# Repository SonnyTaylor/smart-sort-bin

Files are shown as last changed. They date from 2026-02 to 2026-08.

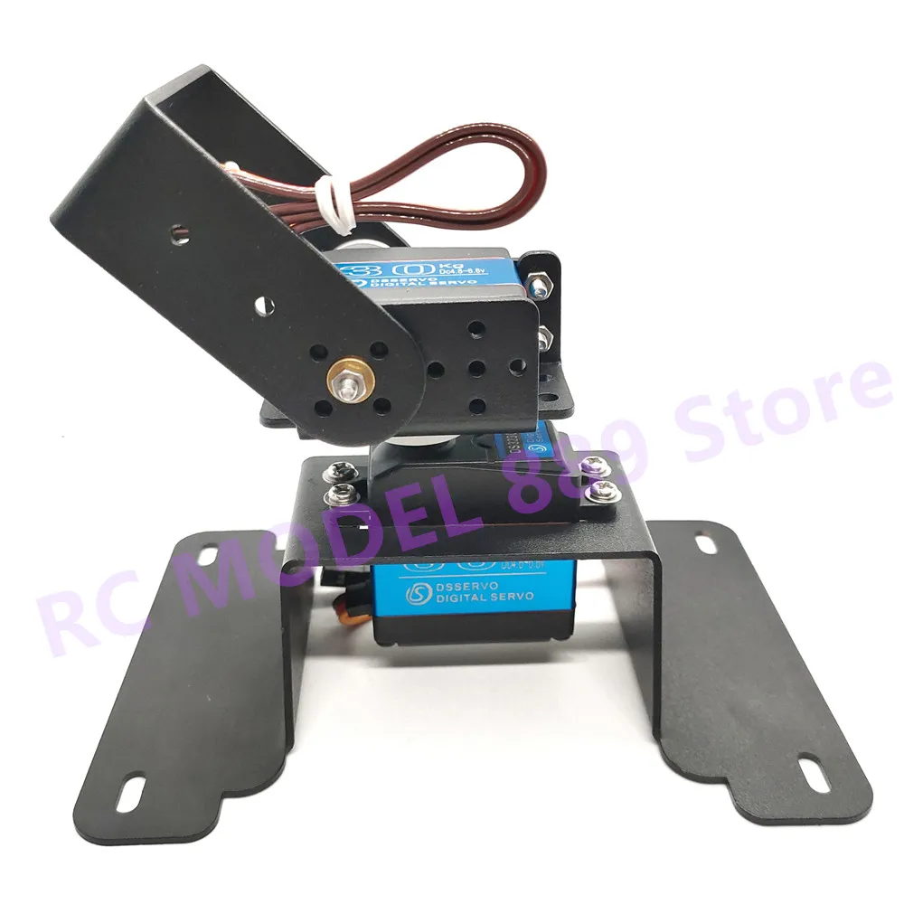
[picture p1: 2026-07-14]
portfolio/images/hardware/premade_bracket.webp

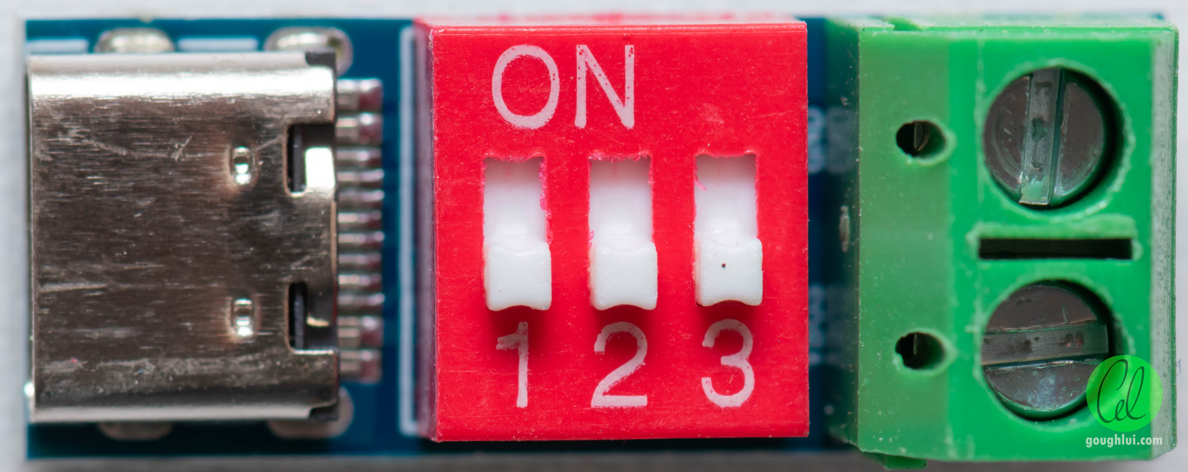
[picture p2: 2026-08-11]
portfolio/images/hardware/usbc_pd_board.jpg

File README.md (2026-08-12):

# Smart Sort Bin





An AI-powered waste sorting system that eliminates recycling contamination at the point of disposal. A camera on a pan/tilt head captures each item, a cloud Vision Language Model classifies it, and servos tip it into one of three bags hanging in the bin, all controlled from a web dashboard.

The head sits on a printed tripod that clamps across the bin rim on three PVC legs. Moving the whole thing to a different bin means cutting three new legs and nothing else.

**Build status:** electronics and software run. None of the eleven printed parts have been made yet. See the [build log](docs/build_log.md).

Developed for VCE Systems Engineering Unit 3 & 4. Inspired by the [Ameru AI Bin](https://www.ameru.com.au/).

---

## Architecture

The prototype runs entirely on a **Raspberry Pi 3B**, pivoted from the original two-board ESP32-CAM design. That iteration is written up in the PowerPoint.

```
  [ Item placed on tray ]
           |
  USB webcam captures frame (v4l2 mmap stream)
           |
  Cloud VLM classifies (OpenRouter / OpenAI / Gemini / Ollama)
           |
  Pan servo -> bin third, tilt servo -> dump, return home
           |
  Sort logged to SQLite, dashboard updates over SSE
```

| Component | Role |
| :--- | :--- |
| Raspberry Pi 3B | Runs Flask server, classification pipeline, servo control |
| USB webcam | Frame capture via `v4l2-ctl` mmap streaming |
| 2x MG996R servos | Pan (GPIO 17) and tilt (GPIO 27) via pigpio hardware PWM |
| WS2812B LED ring | Status colors (GPIO 18). Dropped from the build, code kept |
| USB-C PD trigger board | External 5V rail for servos |

## Web Dashboard

One page at `http://<pi>:8080/`:

- **Camera**: live MJPEG stream, Snap & Sort pipeline with real-time stage progress, classify-only, snapshots, model comparison (two VLMs on the same frame, side by side)
- **Servo control**: XY drag pad, fine sliders, keyboard (WASD) and gamepad input. Inputs are throttled client-side and slew-rate-limited on the Pi so motion is always smooth
- **Animations**: server-side keyframe engine with built-in moves (wave, nod, scan, figure-8, ...) plus a sequence editor to compose, preview, and save your own
- **Calibration**: set each bin's pan/tilt positions from the current head position, tune sequence timing, test a full dump without touching code
- **Stats**: totals, per-category breakdown, confidence/latency averages, 24-hour activity chart
- **Providers**: OpenRouter/OpenAI/Gemini/Ollama/custom, API keys and model IDs editable in the UI with connection tests

## Running Locally (no hardware)

Requires Python 3.11+ and [uv](https://docs.astral.sh/uv/):

```bash
cd src/web
uv run app.py --mock
```

Open http://127.0.0.1:8080. Everything works except the camera feed and physical servo motion.

## Running on the Pi

Run `python tools/deploy.py` to push the code and restart Flask.

The Pi runs `app.py --pi`, which loads the real hardware layer (`src/pi/hardware.py`) and needs the `pigpiod` daemon for jitter-free servo PWM.

The other flags, the wiring, the OS setup and the troubleshooting are all in [`docs/pi_setup.md`](docs/pi_setup.md), which is the one place the deploy commands are written out in full.

## Project Structure

```
smart-sort-bin/
├── portfolio/            # The VCE PowerPoint. ai_bin.js generates it
├── src/                  # The code that runs the bin
│   ├── pi/hardware.py    # Servos (pigpio + slew smoothing), camera, LED
│   ├── systemd/          # Service files for auto-start
│   ├── esp32/            # Dead firmware from the old two-board design
│   └── web/              # Flask app, dashboard, database, VLM providers
├── cad/                  # Fusion exports, plus the design-evolution renders
├── docs/                 # Build log, mechanical design, Pi setup notes
├── tools/                # deploy.py, check_docs.py
└── PLAN.md               # Original project plan, frozen
```

## Documentation

The VCE portfolio is a PowerPoint, generated from
[`portfolio/ai_bin.js`](portfolio/ai_bin.js) by running `bun run ai_bin.js`. It
is the up-to-date record of the risk assessment, budget, testing, iteration
history and evaluation, and it has been submitted once already.

A second deck, [`portfolio/hardware_log.js`](portfolio/hardware_log.js), builds
the hardware development log: how the mechanism was designed, in the order it
happened, and the fifteen faults caught before printing. Run `bun run
hardware-log`.

Everything else has one home, and this is the list of homes:

- [Build log](docs/build_log.md): what has actually been built, dated. **Start here**
- [Mechanical Design](docs/mechanical_design.md): how the sorting mechanism works, with verified clearances
- [Mechanical Iteration Log](docs/mechanical_iteration_log.md): fourteen faults found and corrected before printing
- [CAD](cad/README.md): parts, hardware list and assembly order
- [Design evolution renders](cad/renders/README.md): how the old versions of each part get drawn from git history
- [Pi Setup](docs/pi_setup.md): wiring, OS config, deploy commands, troubleshooting
- [Pi TODO](docs/pi_todo.md): what is left to do
- [Project Plan](PLAN.md): the original plan, frozen as a historical record

If you are an AI agent working in this repo, read [AGENTS.md](AGENTS.md) first.
It has the rules that stop these documents drifting apart, and
`python tools/check_docs.py` enforces them.

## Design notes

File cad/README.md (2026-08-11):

# CAD

The mechanical parts. **Autodesk Fusion is the source of truth.** The models
live in the Autodesk project *Systems engineerring*; everything in this folder
is exported from there.

## The parts

| Fusion document | Qty | Size | What it does |
| :--- | :---: | :--- | :--- |
| Smart Bin - hub plate | 1 | 132 dia x 4 | Holds the pan servo, spans the bin on three legs |
| Smart Bin - leg bracket | 3 | 32 x 26.4 x 36.4 | Bolts under the plate, takes a pipe |
| Smart Bin - bin clamp | 2 | 58.1 x 24.4 x 31.4 | Grips the bin rim at the far end of each pipe |
| Smart Bin - camera clamp | 1 | 58.1 x 26.4 x 66.4 | The same clamp with a 20mm socket on top for the camera post. Replaces one of the three |
| Smart Bin - camera head | 1 | 50 x 32 x 38 | Caps the camera post. Side arm carries a 1/4-20 bolt for the webcam |
| Smart Bin - pan ring | 1 | 96.3 x 111.2 x 11.5 | Traps the pan servo against the plate and carries the yoke's bearing |
| Smart Bin - tilt yoke | 1 | 60 x 116.5 x 62.5 | Turns on the ring, carries the tilt servo out past the tray |
| Smart Bin - tilt cradle | 1 | 52 x 92 x 31 | Tips the tray about the tilt axis |
| Smart Bin - sorting tray | 1 | 120 x 90 x 18 | The saddle the rubbish lands on |
| Smart Bin - box hanger | 1 | 33 x 44 x 26 | Hooks over the bin rim and carries the box below |
| Smart Bin - electronics box | 1 | 71 x 190 x 42.5 | Holds the Pi, breadboard, PD board and wiring |
| Smart Bin - assembly | | | All of the above in position, plus the bin |

Not printed: **four** lengths of 20mm PVC electrical conduit, three for the
legs and one standing up for the camera, plus two MG996R servos.

The head is our own design. It used to be a bought MakerWorld pan-tilt
tracker, which is why some older pictures show a 125mm dome under the tray.
[`docs/mechanical_design.md`](../docs/mechanical_design.md) explains how the
replacement works and why.

### The head, in one paragraph

The pan servo drops through the hub plate and hangs underneath, with its
flange trapped between the plate's top face and the pan ring. The ring's top
face is a plain bearing. The tilt yoke turns on it, bolted to the pan servo's
horn, and reaches out past the edge of the tray on both sides: the tilt servo
on one arm, a 10mm idler boss on the other. The tilt cradle spans between
them and the tray bolts to it. Tilt axis 58mm above the plate, tray underside
73mm.

### The camera post

The post goes on the **180 degree leg**, the long one, and is in the assembly.
Its axis sits 142.5mm from the tray centre, and the tray only sweeps a 75mm
radius when it pans, so nothing moving comes near it.

The camera itself sits on the head's side arm, which reaches back toward the
tray, so the **bolt axis is 122.5mm** from the tray centre. That is the number
every sighting figure below is worked from, not the post's own 142.5.

With a **235mm** length of conduit the arm's top face finishes at z=238, and the
tray's surface at its centre is at z=81, so the camera sits 157mm above the tray
and 122.5mm to one side. That is looking down about **52 degrees** from **199mm**
away. A longer pipe gives a steeper, more overhead view: the camera ends up
roughly `122.5 x tan(angle)` above the tray surface.

This was 300mm when the tray sat 65mm higher. Cutting a 300 now gives 61 degrees
from 254mm away, which still works and is actually a squarer view of the tray,
but it puts the camera further off and stands the whole thing taller.

The webcam mounts with a **1/4-20 bolt** through the head's side arm, head
recessed underneath, thread pointing up. The arm sticks out toward the tray so
the pipe is not in shot and so the bolt head is reachable.

**The post locks with an M3 screw** through a pad on the outboard side of the
socket, 26mm above the rim. The socket wall on its own is 2.97mm, too thin to
take a brass insert, so the pad stands 4mm proud of it and gives the insert its
full 5mm. Aim the camera first, then tighten. The screw tip reaches 3mm into the
bore and bites the conduit.

## The electronics box

It goes on one of the **long side walls, on the outside**, centred 63mm from the
middle of that wall toward the camera-post end. That leaves 15.5mm to the bin's
corner and 14.8mm to the nearest leg clamp, which is the tightest pair of
clearances on the part. It sticks out 77mm from the wall and hangs 42.5mm below
the rim. Nothing about it is tied to that spot; it can go anywhere there is
190mm of clear rim.

The hanger goes on first and stays there. Its thumbscrew enters **from inside
the bin**, so it is set once, before the bags go in, and the box then lifts on
and off without touching it. The box's top edge finishes level with the rim, so
cables from the hub and the camera post cross the rim and drop straight in
through the 10mm gap between the box's back wall and the bin.

Inside is **185 x 62 x 40mm**. A Raspberry Pi 3B and a half-size breadboard lie
side by side along the floor with 17mm to spare. **Measure your breadboard
first:** this is sized for the half-size 83 x 55mm board in the prototype
photos, and a full-size 165mm one will not fit beside the Pi.

Four pegs in the floor match the Pi's own 58 x 49mm hole pattern and stand it
3mm clear. The board drops on and no screws are needed.

## Folders

| Folder | Use |
| :--- | :--- |
| `stl/` | **Print from here.** Exported from Fusion at high refinement |
| `step/` | Solid models for anyone who wants to open the parts elsewhere |
| `renders/` | Makes the design-evolution pictures for the portfolio, by rendering old versions of parts out of git history. See [`renders/README.md`](renders/README.md) |
| `*.scad` | The OpenSCAD source the hub and tray were originally developed in. No longer the design source, but **do not delete**: the version history in these files is what `renders/` draws the superseded designs from |

## Exporting after a change

Open the assembly document and run
[`renders/export_from_fusion.py`](renders/export_from_fusion.py) inside Fusion.
It writes all nine parts to `stl/` and `step/` in one go, and refuses to run if
the assembly is sitting on an out-of-date version of a part.

By hand, if you prefer: **Utilities > Make > 3D Print** for STL, **File >
Export** for STEP, saved into `stl/` and `step/` under the same name.

Either way, commit the exports. They are the only copy of a Fusion part that
lives in git, and the design-evolution renders draw the current version of each
part from them.

Renders of the finished parts come out of the Fusion assembly document and land
in `../portfolio/images/cad/`.

Renders showing how a part **changed over time** are made by
[`renders/`](renders/README.md) instead, and land in
`../portfolio/images/cad/evolution/`. Those are generated from git history, so
after changing a part, re-run them and the "current" panel updates itself.

## Cutting the pipes

Three different lengths, because a three-legged thing does not sit on a
rectangle symmetrically. For the 60L ecobin (347 x 277 outside, 4.5mm corflute):

| Leg | Cut to |
| :--- | :--- |
| 60 deg | 103.73 mm |
| 180 deg | 118.00 mm |
| 300 deg | 103.73 mm |
| camera post, standing up off the 180 deg clamp | 235 mm |

Change the bin and the three leg lengths change. The old `splitter_hub.scad`
still works out the figures from bin dimensions if you need them for a
different bin. The camera post does not depend on the bin, only on how steeply
you want the camera to look down.

## Hardware

24 x M3 brass heat-set inserts: 6 in the bracket feet, 6 in the pipe lock pads,
3 in the clamp jaws, 3 in the pan ring, 4 in the tilt cradle, 1 in the box
hanger, 1 in the camera post lock pad.

| Qty | Screw | Into |
| ---: | :--- | :--- |
| 6 | M3 x 8 countersunk | plate, down into the bracket feet. **Not longer:** past 9mm it bottoms out |
| 6 | M3 x 8 | pipe locks, down through the pads onto the conduit |
| 3 | M3 x 10 | up through the plate's spokes at R=50 into the pan ring. These are what clamp the pan servo |
| 4 | M3 x 12 countersunk | tray, down into the tilt cradle |
| 1 | M3 x 10 + washer | through the cradle's idler wall into the yoke's boss. Self-taps into a 2.5mm pilot |
| 3 | M3 x 16 or 20 | clamp thumbscrews. 16 leaves 2.4mm of travel, 20 leaves 6.4mm |
| 1 | 1/4-20 UNC x 12 or so | camera head, up through the side arm into the webcam. Hex head sits in the 11.5mm recess underneath. Any tripod screw works |
| 1 | M3 x 16 | box hanger jaw, entering from **inside** the bin. Crosses a 7.5mm gap to a 4.5mm wall with 3.5mm to spare. A 20 also fits |
| 1 | M3 x 10 | camera post lock, through the pad on the socket. Reaches 3mm past the bore onto the conduit |

The servos are fixed with **the small screws that came in their own bag**, not
with M3:

| Qty | Screw | Into |
| ---: | :--- | :--- |
| 4 | servo mounting screws | tilt servo flange, into 2.5mm pilots in the yoke's tower wall |
| 4 | servo horn screws | pan horn, up into the yoke's skirt |
| 4 | servo horn screws | tilt horn, through the cradle's driven wall |

**The pan servo takes no screws at all.** Its flange sits in a 2mm pocket and
the pan ring clamps it down; the case sits in a 41.6 x 21mm slot which is what
actually takes the panning torque. That is deliberate, and the reason is in
[`../docs/mechanical_iteration_log.md`](../docs/mechanical_iteration_log.md).

## Assembly order

1. Melt the inserts in. Everything is easier before anything is bolted together.
2. Bracket feet to the plate, countersunk screws from above so the heads finish
   flush.
3. Pipes into the brackets, lock screws down through the pads.
4. Clamps onto the far ends of the pipes, lock screws down. The **camera clamp**
   goes on the 180 degree leg, the long one.
5. Drop the assembly over the bin and nip up the three thumbscrews.
6. **Pan servo down through the plate's centre slot from above**, cable first,
   body hanging underneath, flange flat on the plate. The body points along the
   180 degree spoke, the same way as the long leg.
7. Pan ring over it, three M3 x 10 up through the plate's spokes. The ring
   traps the flange; nothing screws into the servo.
8. Tilt servo into the yoke's tower, its four own screws through the flange.
9. Pan horn onto the pan servo's shaft, then the yoke down onto it. Four horn
   screws up through the skirt, then the servo's centre screw through the 9mm
   hole in the middle. **The yoke's weight sits on the ring, not on the horn.**
10. Tilt horn onto the tilt servo's shaft. Cradle over it: horn into the pocket
    in the driven wall, four horn screws, then the idler screw and washer
    through the far wall into the yoke's boss.
11. Tray onto the cradle, four countersunk screws.
12. Camera post into the camera clamp's socket, head onto the top of it, webcam
    bolted to the head's side arm. Aim it before you tighten anything.
13. Box hanger over the rim on a long side wall, thumbscrew tightened from
    inside the bin. Then drop the electronics box onto its cleat. The box only
    goes on one way round, and it lifts straight off again.

Centre both servos in software before step 9, or the head will be built at an
angle and the whole travel will be off to one side.

## Three things to measure before you print

**The tilt servo's flange holes.** The yoke's four pilot holes are on a
48 x 8.5mm pattern, taken off the servo model. The figure quoted in most places
online is 49.5 x 10mm. Those cannot both be right, and 0.75mm a side is enough
to stop the screws going in. Put calipers across the real flange. Nothing else
in the design depends on this number, on purpose, but the yoke does.

**The servo horns.** The yoke and the cradle each have a 25.5mm round pocket for
a horn, with four 2.5mm pilots on a 16mm circle. MG996R horns vary between
sellers. Measure yours and say so if it is not a 25mm round one.

**The inserts.** M3 inserts run 4.0 to 4.6mm outside depending on supplier. Every
insert hole here is 4.2mm. Measure yours, and if they differ the holes need
changing before you print anything.

## Printing

Printer is a **Bambu Lab P1S**, 0.4mm nozzle, PLA. Fourteen pieces off eleven
designs. Everything fits the 256mm bed with room to spare; the longest part is
the electronics box at 190mm.

Every orientation and support call below was worked out from the exported
meshes, not from looking at renders. For each of the six ways a part can sit,
the downward-facing area was measured and split into patches that share an
edge, so a window's short bridge is not confused with a curved surface hanging
in air. A patch is treated as bridgeable up to 12mm across its narrow way.

### Orientation and support, part by part

The STLs are exported in the orientation the part is modelled in, so "as
loaded" means drop it on the plate and print. Where a rotation is needed, apply
it in the slicer and **check the height matches**: that is how you know you
rotated the right way, since the wrong way round gives the same footprint.

| Part | Qty | Rotate | Height when right | Support |
| :--- | :---: | :--- | ---: | :--- |
| plate | 1 | As loaded, either way up | 4.0mm | None |
| bracket | 3 | -90 about Y | 32.0mm | None |
| clamp | 2 | As loaded | 31.4mm | None |
| camera_clamp | 1 | 180 about X | 66.4mm | One patch, 20 x 21mm |
| camera_head | 1 | As loaded | 38.0mm | None |
| pan_ring | 1 | As loaded | 11.5mm | None |
| tilt_yoke | 1 | As loaded | 62.5mm | One patch, 25.5 x 25.5mm |
| tilt_cradle | 1 | 180 about X | 31.0mm | None |
| tray | 1 | As loaded, trough up | 18.0mm | Yes, most of the underside |
| box_hanger | 1 | 180 about X | 26.0mm | None |
| electronics_box | 1 | As loaded, open side up | 42.5mm | None |

`tray_mount` is not in the build, but it is worth printing as a test rig, see
below. It goes **180 about X**, 18.0mm tall, no support.

**Eight of the eleven need no support at all**, which is the payoff from the
45 degree flanks the sockets were given when they were shelled. Three do:

- **camera_clamp**: 363 mm2 at 27mm up, the roof that closes the camera post's
  socket and stops the pipe pushing through. Flat and 20mm across, too wide to
  bridge.
- **tilt_yoke**: 427 mm2 at 3mm up, the roof of the 25.5mm servo horn pocket.
- **tray**: about 8.6 cm2, nearly the whole underside.

### What kind of support

**Normal, not tree, and "on build plate only" for all three.** Each overhang
was checked by dropping a ray from the middle of it: all three have clear air
straight down to the plate, so the support stands on the bed and never has to
start on the part.

That one setting is also the safety catch. On "everywhere" the slicer is free
to fill the blind insert holes and the pipe sockets, because those have model
material at the bottom for support to sit on. On "build plate only" it cannot,
so the holes stay clear without anyone having to police them.

Tree support is the wrong shape for all three of these. Two are single flat
roofs, which normal support handles with a plain block, and the third is inside
a 20mm tube, where a tree tangles and will not come out.

| Part | The support is | Getting it off |
| :--- | :--- | :--- |
| tilt_yoke | a 25.5mm disc, 3.2mm off the plate. Three layers of nothing | Lifts off. It is the horn pocket, so a rough face there does not matter |
| camera_clamp | a 20mm column 27mm tall, standing inside the socket bore | The bore is open at the bed, so push the column straight out with a screwdriver from underneath |
| tray | a bed of support under most of the underside, carrying the part | Peels off. Only the four bolt pads matter, and support leaves those flat |

Set **top Z distance to one layer, 0.2mm**, so support breaks away instead of
welding on. On the camera clamp keep the interface layers low for the same
reason: that face is only an end stop for the conduit and it wants to come
apart cleanly, not look nice.

The tray is the one carrying real weight on its supports, since the part
balances on two end edges with no flat contact anywhere. Give it a **brim** and
do not run the support density down to the sparse end.

Turn support **off** for everything else. Left on auto, the slicer will put
support inside the pipe sockets and the insert holes, and digging it back out
of a 20mm bore is worse than the problem it solves.

### The tray is the awkward one

It is a saddle: a trough running the long way that the rubbish lands in, with
the sides raised 7.7mm to stop things rolling off, and both ends falling away
5.8mm so the load slides out when it tips. That shape has **no flat face
anywhere**, so laid down it touches the bed on two end edges and nothing else.

Print it **trough up, with supports**, and add a brim. Two reasons, and neither
is about saving support material:

- The trough is the surface rubbish has to slide off. Support marks belong on
  the underside, which only meets the cradle at four bolt pads.
- Laid flat the layers stack the way the load presses them together. Stood on
  end, which does cut the support from 8.6 to 0.3 cm2, the layers become
  vertical planes and the saddle can split along one under a side load, on a
  part 120mm tall standing on 36 mm2 of bed.

If it does come out badly, standing it on end is the fallback, not the plan.

### Settings

Starting point, not gospel. Nothing here has been printed yet.

| | |
| :--- | :--- |
| Layer | 0.2mm |
| Walls | 4 on the brackets, clamps, yoke and cradle. 3 elsewhere |
| Infill | 25% gyroid on anything holding a load, 15% for the electronics box |
| Brim | Tray and camera clamp only |

Four walls where the brass inserts go, because an insert melted into a 4.2mm
hole eats most of a 3-wall skin and the screw then pulls out through the side.

**Leave the door open and the glass lid off.** The P1S is enclosed, and PLA on
a long print in a hot chamber softens in the throat and jams. None of these
parts needs the enclosure.

### What to print first

**It depends on what you have in your hands**, because a test print is only
worth printing if there is something to check it against.

**Once the conduit and the inserts arrive, print one bracket.** It is the
smallest structural part at 14.7 cm3 and the only one that tests three of the
unknowns above at once: an insert hole, a socket that has to fit real 20mm
conduit, and an M3 lock screw. Melt an insert in, push an offcut of conduit
into the socket, and drive the lock screw before committing the other thirteen
pieces. If those fit, the rest follows in assembly order.

**Before then, the bracket proves nothing**, and neither do the clamps, the
camera clamp, the plate, the box or the hanger. Every one of them is checked
against the bin, the conduit or the inserts. What can be checked today is
whatever meets the **servos, the horns and the webcam**, since those are
already here:

| Print | cm3 | What it settles |
| :--- | ---: | :--- |
| camera head | 18.8 | The webcam's 1/4-20 screws into the side arm. No support, quick |
| tilt yoke | 39.3 | The tilt servo's flange pattern, which is the one number in this document most likely to be wrong, plus the 25.5mm horn pocket |
| tray + tray mount | 48.6 | A working tip test on the bought pan-tilt, before any of the new head exists |

**The tray and the tray mount are the interesting pair.** `tray_mount` is a
superseded part and is not in the final build, but it is the adapter between
the tray's four bolts and the bought MakerWorld pan-tilt, so printing the two
together puts a real tray on a real moving head now. Measured off the meshes:
the tray's four 3.4mm holes and the mount's four 4.2mm insert holes are both on
a 32 x 15mm pattern, and the mount takes two more screws 15mm apart underneath
into the bought bracket.

That rig tips actual rubbish, which is the only thing on this list that tests
whether the design works rather than whether it fits. It needs four brass
inserts in the mount, so if those have not arrived, dry-fit it and hold it
together for the test rather than waiting.

### How much filament

| | cm3 | PLA at 1.24 g/cm3 |
| :--- | ---: | ---: |
| All 14 pieces, solid | 354.5 | 440 g |
| Sliced estimate, walls and infill | | **200 to 265 g** |

The solid figure is measured off the meshes and is exact. The sliced figure is
an estimate at 45 to 60% of solid, which is the usual range for parts this
chunky at these wall and infill settings. Only the slicer knows the real
number. Either way a 1kg spool covers the build with room for a reprint.

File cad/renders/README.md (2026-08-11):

# Design evolution renders

This folder makes the "here is how the design changed" pictures for the
portfolio.

Two sources, and the split matters:

- The **current** version of each part is rendered from a **Fusion export**,
  because Fusion is the design source of truth.
- The **superseded** versions are rendered from the OpenSCAD files **as they
  were at the commit they lived in**. Those versions predate the move to
  Fusion, so git history is the only place they still exist.

Either way the images are the real designs rather than something redrawn
afterwards. That is the point: evidence, not illustration.

Output lands in [`../../portfolio/images/cad/evolution/`](../../portfolio/images/cad/evolution).

| File | What it is |
| :--- | :--- |
| `<family>.png` | The comparison strip: every version of one part, left to right, with a caption under each |
| `parts/<stage>.png` | Each version on its own, cropped, if you want to place one somewhere else |

---

## Running it

Three steps. Export from Fusion, render, lay out.

**1. Export the current parts from Fusion.** Open the *Smart Bin - assembly*
document, then run [`export_from_fusion.py`](export_from_fusion.py) inside
Fusion, either through the Fusion MCP connector or Fusion's own Scripts and
Add-Ins dialog. It writes `cad/stl/` and `cad/step/`, and refuses to run if the
assembly is sitting on an out-of-date version of a part.

Skip this step only if no part has changed in Fusion since the last time you ran
it.

**2 and 3. Render and lay out.**

```powershell
cd cad\renders
.\render.ps1
python compose.py
```

Takes about three minutes, most of it the tray, which has a curved surface and
20,000-odd facets.

Working on one part only:

```powershell
.\render.ps1 -Only tray
python compose.py tray
```

Seeing what would run without running it:

```powershell
.\render.ps1 -WhatIf
```

**Needs:** OpenSCAD (path is in `stages.json`) and Python with Pillow
(`pip install pillow`).

---

## Adding a new version

Everything is driven by [`stages.json`](stages.json). To add a version, add an
entry to that part's `stages` list. Nothing else changes.

```jsonc
{
  "name": "tray_4_ribbed",          // the output filename
  "label": "v4",                    // shown above the caption. "current" prints in red
  "source": { "file": "cad/tray.scad", "part": "tray" },
  "caption": "What changed and why.\nKeep it to three lines."
}
```

A stage's `source` is one of three things:

| Source | Renders | Use for |
| :--- | :--- | :--- |
| `{"stl": "cad/stl/plate.stl"}` | A Fusion export | **The current version of anything.** Fusion is the source of truth |
| `{"commit": "abc1234", "file": "cad/tray.scad", "part": "tray"}` | That file as it was at that commit | Superseded versions, which predate Fusion |
| `{"file": "cad/tray.scad", "part": "tray"}` | The OpenSCAD working copy | A part that never made it into Fusion, like the spacer |

Find the commit for a past version with:

```powershell
git log --oneline --follow -- cad/tray.scad
```

### Turning the current version into history

When a part changes enough to be worth a picture, the old "current" panel
becomes a historic one. Since the current panel is a Fusion export and Fusion
versions do not live in git, capture it **before** you change the part:

1. Run the export script and commit the STL, so that geometry is pinned in git
   history under a commit you can name.
2. Change the part in Fusion.
3. Re-export, then add a stage pointing at `{"commit": "<that commit>", ...}`.

If you forget, the old shape is still in Fusion's own version history, which you
can open from the data panel and export from.

### Why the OpenSCAD files still matter

The hub and tray were originally drawn in OpenSCAD and have since been rebuilt
in Fusion. The `.scad` files are no longer the design source, but their git
history is the only copy of the early versions. That is why they stay in the
repo.

---

## The bits that were fiddly

Worth knowing before changing the scripts, because each of these cost time.

**Parts stay comparable in size.** Every version of one part is rendered from
the same camera distance (`camera` in `stages.json`, shared by the family), and
`compose.py` then scales the whole family by a single factor. This is what makes
"the plate went from 160g of filament to 84g" visible instead of just claimed.
Do not let the layout scale each image to fit its own box.

**Full geometry, not preview.** `--render=cgal`. Without it OpenSCAD draws the
fast preview, where coincident faces z-fight and parts come out striped orange.
Note that this build of OpenSCAD needs a value: plain `--render` is a usage
error.

**PowerShell has to be told to wait.** `openscad.exe` is a GUI binary, so `&`
does not reliably block until it finishes and the script races ahead to an image
that is not written yet. Hence `Start-Process -Wait`.

**Which also has to be told to quote.** `Start-Process -ArgumentList` joins an
array on spaces without quoting anything, and this repo lives under
`C:\Users\Sonny Taylor\`, so every path split in half and OpenSCAD printed its
usage message. The script quotes the arguments itself.

**Choosing the part.** These `.scad` files build one part at a time, chosen by a
`PART` variable near the top. Rather than pass `-D PART="clamp"`, which is
awkward to quote through PowerShell into a native binary, the script rewrites
that one line in a scratch copy. It errors if it cannot find the line, so a
renamed variable will not silently render the wrong thing.

**The background is dropped out.** `compose.py` treats the render's top-left
pixel as the background colour and cuts everything matching it, keeping the
soft edge so the part does not look jagged. That is why the strips sit on white
rather than on OpenSCAD's grey.

---

## What is in here

| Path | |
| :--- | :--- |
| `stages.json` | The manifest. The only file you normally edit |
| `export_from_fusion.py` | Run inside Fusion. Writes the current parts to `../stl/` and `../step/` |
| `render.ps1` | Renders each version, from a Fusion export or from git history |
| `compose.py` | Crops the renders and builds the labelled strips |
| `raw/` | Untouched renders. Regenerated, not committed |
| `src/` | The scratch `.scad` files pulled from history. Regenerated, not committed |
| `logs/` | OpenSCAD's output per stage, including the model's own echoed calculations. Look here when a render fails |

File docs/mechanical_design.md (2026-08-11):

# Mechanical Design

*How the sorting mechanism works and why it is shaped the way it is. The
iteration history behind these decisions is in
[mechanical_iteration_log.md](mechanical_iteration_log.md).*

---

## The problem

Sort an item into one of three compartments of an ordinary wheelie-style bin,
without modifying the bin, using two servos.

## The solution in one line

A printed tripod clamps across the bin's rim and carries a pan-tilt head. The
item lands on a tray, the head turns to face a compartment, the tray tips, and
the item free-falls in.

---

## 1. The tripod hub

Three lengths of 20mm PVC electrical conduit radiate from a printed plate to
three clamps that grip the bin rim.

**The legs are structure, not chutes.** Rubbish never goes through them. It tips
off the tray and falls past them. This is what keeps the mechanism small: the
only thing that has to be printer-sized is the hub, and the span is a pipe you
cut to length.

**Bin size is a pipe length.** Changing bins means cutting three new pipes, not
reprinting anything. For the 60L ecobin the three legs come out at 103.73,
118.00 and 103.73mm, and the fact that they differ is exactly the point: three
legs at 120 degrees cannot reach the walls of a rectangle at equal distances.

This is the design's main idea, and every other decision protects it. The clamp
shape (below) is what lets it grip a bin of any shape, and using bags rather
than cut dividers (section 4) is what stops the compartments tying it back to
one bin.

### Why the legs sit at 60, 180 and 300 degrees

The drops go at 0, 120 and 240, midway between the legs. If they lined up, the
tray would fling items straight into a leg.

It also means **the legs are the dividers**. Three legs 120 degrees apart cut
the bin opening into three sectors, and each drop aims at the middle of one. No
separate divider part is needed, which is the second job the legs are already
doing.

### Why the clamp is shaped oddly

Three legs at 120 degrees cannot all meet a rectangular bin's walls square on.
On the ecobin one leg is square to its wall and the other two are 30 degrees
off.

So the fixed jaw is a **vertical rounded rib**, which touches the wall along a
line, and the thumbscrew pushes a **single point** at it from the other side. A
line plus a point pinches at any angle. The same clamp therefore grips a
rectangular bin, a round bin or a cardboard box, with no adjustment.

The outer post is deliberately narrow at 9mm. A wall arriving at an angle sweeps
sideways across the jaw, and a wide outer plate would foul it before it seated.

### Printing without supports

Every pipe socket bore is a **truncated teardrop**, not a circle: a flat-topped
45 degree peak over a round bore. That is what lets a sideways hole print with
no support. A round pipe still slides in.

### Why the sockets are shells, not blocks

A pipe socket is a round hole in a square block, so its wall is thin where the
bore is widest and thick in the four corners. Measured on the old clamp: 1.49mm
at the equator and 6mm in the corners, for a block that was 36% plastic and 64%
air. The corners were carrying nothing. They were there because a rectangle is
what you get when you extrude a rectangle.

The outer face now **follows the bore**, offset 2.5mm, with 45 degree flanks so
it still prints without support. The result is a constant-thickness shell that
is nowhere thinner than the wall it replaced, and the six socketed parts drop
from 114.3 to 95.0 cm3.

Two corners are kept rather than cut, and the reason is the same in both cases:

| Part | Bottom corners | Why |
| :--- | :--- | :--- |
| Bin clamp | cut | Nothing is under the block. Its load goes sideways into the jaw |
| Camera clamp | kept | The block's underside **is** the lid of the post socket and the seat the post's end butts against |
| Leg bracket | kept | The tube walls are 25mm apart and have to land on the foot. Cutting them pinched the load path to a 9mm strip |

So the rule is: **cut a socket's corners only where nothing is attached below
it.** Above the bore, where every one of these parts is open air, the corners
always go.

---

## 2. The tray

A shallow saddle, 120 x 90mm, 3mm shell. Mathematically a hyperbolic paraboloid:

```
z = 10 * (y/45)^2  -  5 * (x/60)^2
```

**No rim anywhere.** A rim would trap the item exactly when you are trying to tip
it out, which is the opposite of the job. The surface runs out to a thin edge.

| Direction | Shape | Why |
| :--- | :--- | :--- |
| Across (the tilt axis) | curls **up** 10mm | When the head pans, the item is thrown sideways. This gentle valley rolls it back to the middle. It is the only retention there is, and it works with gravity rather than blocking anything |
| Along (the dump direction) | curls **down** 5mm | Where the item leaves. Curling down means there is nothing to climb, so it goes as soon as it tips |

**Why 5mm and not more.** At 5mm the steepest slope is 9.5 degrees, well under
the roughly 19 degrees at which plastic starts sliding on PLA. So the item stays
put until the tray is actually tipped. Past about 8mm you are relying on luck.

Print it matte white or grey. The camera classifies the item against this
surface, so a busy or shiny background costs accuracy.

---

## 3. The head

The head was a bought MakerWorld pan-tilt tracker. It is now three printed
parts of our own, because the bought one put the tray **147mm above the bin
rim** and 85mm of that was its own stacking. The measurements, and the reason
it could not just be shimmed lower, are in
[mechanical_iteration_log.md](mechanical_iteration_log.md).

### Why a hobby pan-tilt is tall

A standard pan-tilt stands its tilt servo on end inside a U-bracket. An MG996R
is 40.7mm long with its output shaft 10.2mm off centre, so mounted that way the
**body finishes 37mm above the tilt axis**. The tray then has to clear the
servo before it clears anything else, and that alone sets the height. Everything
below it, the base and the pan servo, is stacked underneath again.

### What replaced it

**The pan servo drops through the hub plate.** Its flange sits in a 2mm pocket
on the plate's top face and the *pan ring* clamps it there; the body hangs
underneath, inside the bin, where there was nothing anyway. That deletes the
tracker's 125mm dome outright, and with it the 27mm the dome stood above the
plate and the 14.5mm gap above the servo.

**The tilt servo goes beside the tray, not under it.** This is the part that
buys the height. Hanging it below the tilt axis was tried first and does not
work: the tray sweeps a circle about that axis, so at 45 degrees of backward
tilt it comes down into the servo. But the tray is only 90mm wide and it tilts
about a **y-parallel axis**, so it sweeps in x only. Move the servo out past
y = 45mm and the tray can never reach it, at any angle.

So the *tilt yoke* turns on the ring and reaches out past both edges of the
tray: the tilt servo on one arm, a 10mm idler boss on the other. The *tilt
cradle* spans between them and carries the tray.

### What sets the height now

Not the servos. **The tray's own swing.** At 60 degrees its far corner reaches
44.5mm below the tilt axis, so the axis cannot come closer than that to the hub
plate. The axis sits at z=58 and the tray's underside at z=73, which is 82mm
above the bin rim against 147mm before.

| | Before | After |
| :--- | ---: | ---: |
| Tray underside above the rim | 147 mm | 82 mm |
| Plastic in the head | 138.4 cm3 | 100.8 cm3 |
| Printed parts in the head | 4 bought + mount | 3 |

### How far it can actually tip

The dump angle is a software number set from the Calibration tab, and **the
mechanism runs out before the servo does.** Measured by swinging the exported
tray mesh about the tilt axis, which was read off the cradle's horn pocket and
the yoke's idler boss at x=0, z=58, and checking it against the pan ring and
the hub plate:

| `tilt_dump` | Angle | Tray's lowest point | Gap to the pan ring |
| ---: | ---: | ---: | ---: |
| -0.60, the default | 54 deg | z = 18.3 | **8.3 mm** |
| -0.67 | 60 deg | z = 13.5 | 5.1 mm |
| -0.78 | 70 deg | z = 6.7 | 1.6 mm |

Contact lands somewhere near -0.85. Under about 2mm these figures are vertex
to vertex on a tessellated mesh and should not be read finer than that.

**Keep `tilt_dump` at -0.70 or shallower.** The Calibration tab accepts
anything down to -1.0 and there is nothing in the mechanism to stop the tray
arriving at the pan ring. This is deliberately not clamped in code: what a
given number means in degrees depends on which spline tooth the horn went onto,
so the real limit has to be found when the head is first assembled and centred.
Find it then, by hand, before running a sort.

This is also the answer to whether the head can be made shorter. It cannot, by
much. Lowering the tilt axis spends that 8.3mm one for one, so there is about
5mm in it before the tray starts clipping the ring at the normal dump angle.

### The bearing

The yoke's weight sits on the pan ring's top face, not on the servo horn. A
servo spline is for torque, not for carrying a cantilevered tray. The horn only
turns the yoke; a 60mm annular face takes the load and the overturning moment
from the tilt servo hanging out at y=66.

### Nothing screws into the pan servo

Its flange is trapped rather than bolted. The servo model gives the flange hole
pattern as 48 x 8.5mm and the figure quoted online is 49.5 x 10mm, and those
cannot both be right. A clamp does not care. The case sits in a 41.6 x 21mm
slot, and that is what takes the panning torque.

---

## 4. The three compartments

Three ordinary bin bags, bulldog-clipped to the rim and to the two legs either
side of them. One bag per sector. **No divider part is printed or cut**, because
the legs already divide the opening.

### Why this works, in numbers

Measured off the assembly with the bin in place:

| | |
| :--- | :--- |
| Tray underside above the bin rim | 82 mm |
| Tray underside above the bin floor | 202 mm |
| Item leaves the tray at a radius of | about 60 mm |
| Fall time from that height | 0.20 s |
| Bin wall along the three drop directions | 169, 155, 155 mm |

At a slow tip, roughly 0.3 m/s, an item lands about 120 mm from the centre. At
0.8 m/s it would reach 220 mm, which is past the wall.

The important consequence: **nothing lands near the middle.** The three sectors
converge at the hub, and that is exactly where no item falls, so the one place
bags would fight each other never gets used.

### What this trades away

- Bags sag, and once fairly full they bulge into each other. This is a
  three-quarters-full solution, not a brim-full one. Rigid dividers would not
  have that problem.
- The landing distance spread above is wide enough that a fast tilt throws items
  at the wall. **Tip speed has to be calibrated on the real thing.** It is a
  software number rather than a reprint, which is the advantage of doing the
  motion with servos.

### Why not corflute dividers

Corflute was the original plan and was in the budget. Bags win on the things
that come up every time you use it: a bag lifts straight out, where corflute
means lifting rubbish over a wall; a bag holds liquid; it is about $5 against
$15; and it needs no cutting and no new CAD.

**But the real reason is that corflute would have broken the one property the
whole design is built around.**

The clamp is deliberately shaped to grip a rectangular bin, a round bin or a
cardboard box, and changing bins is meant to cost nothing but three new pipe
lengths. Corflute dividers would have undone that: every new bin needs three
panels cut to that bin's exact cross-section, and a round bin needs curved ones.
The adaptable half of the design would have been dragged back down to one
specific bin.

Bags do not care what shape the bin is. So the fit-any-bin claim now holds all
the way through:

| To move the whole thing to a different bin | |
| :--- | :--- |
| Printed parts | none change |
| PVC legs | cut three new lengths |
| Clamps | no adjustment, they pinch at any angle |
| Compartments | clip the bags to the new rim |

That is the entire changeover. Three saw cuts.

---

## 5. Getting three bins out of a 180 degree servo

Tilting the tray **backward** throws the item 180 degrees opposite to where the
pan is aiming. Every pan position therefore covers two directions, and three
drops 120 degrees apart need only 120 degrees of pan:

| Drop | Pan | Tilt |
| :--- | :--- | :--- |
| 0 deg | 0 | forward |
| 120 deg | 120 | forward |
| 240 deg | 60 | backward |

Without this the mechanism would need 240 degrees of pan and a servo upgrade.

---

## 6. Where the electronics live

The Pi, the breadboard, the PD trigger board and the wiring hang in a box on the
**outside** of the bin rim, on a separate hanger that stays on the bin when the
box is lifted off.

### Why not underneath

Underneath the hub is the obvious place and it does not work. The three leg
brackets hang to 27.4mm below the rim, so a box has to start below them, and
that is exactly where the three bags converge. Getting the Pi out would mean
reaching through the rubbish, and the box would have to bolt to the hub plate.
Outside the rim costs nothing but 77mm of stick-out and keeps the electronics
clean, dry and at hand height.

### The weight goes into the rim, not into friction

The tripod's three clamps hold themselves on by pinching the wall between a rib
and a thumbscrew. That works there because the plate spans the bin and the load
is shared three ways. One hanger carrying about 300g on a 33mm arm is a
different problem, so the hanger **hooks over the rim** instead: a slot with a
flat roof sits on the top edge of the wall and the thumbscrew only stops it
lifting or sitting crooked.

The jaw itself is the bin clamp's, unchanged in principle: a vertical rounded
rib on one side, a single screw point on the other, so it grips a rectangular
bin, a round bin or a cardboard box. The fit-any-bin property survives.

### Why it is two parts

An open-topped box prints open side up, every wall vertical and nothing
overhanging. A hook over the rim has to open **downward**, so built into the box
its inner leg would begin in mid air and need support material through the one
slot whose fit matters. Split in two, each part prints in its best orientation:
the box open side up, the hanger standing up with the slot's flat roof bridging
15mm.

The split pays for itself twice more. The box lifts off without disturbing the
jaw's setting, and the thumbscrew can be reached with the box hanging, because
it enters from inside the bin.

### The numbers

| | |
| :--- | ---: |
| Inside the box | 185 x 62 x 40 mm |
| Sticks out from the bin wall | 77 mm |
| Hangs below the rim | 42.5 mm |
| Gap between the box's back and the bin wall | 10 mm |
| Box, with windows | 62.0 cm3 |
| Box, if the walls were solid | 85.2 cm3 |
| Hanger | 18.1 cm3 |

The 10mm gap matters: bins taper, and the box hangs off the hanger rather than
resting on the wall, so a sloping wall does not push it off plumb.

The windows are the same argument as the pipe sockets in section 1. A plain
walled box is 85.2 cm3 and most of that plastic is doing nothing, so the walls
are cut to a frame, which takes 27% off and vents the Pi at the same time. The
floor slots do the same job and let anything spilt drain out.

---

## Verified clearances

These were measured against the assembled model rather than estimated.

| Check | Requirement | Actual |
| :--- | :--- | :--- |
| Whole assembly, everything against everything | no interference | no printed part touches another. Five overlaps against reference geometry, see below |
| Tray through its tilt range | clear from -60 to +60 degrees | clear; first contact at -65 |
| Tray's lowest reach at 60 degrees | calculated 13.54mm | 13.51mm measured on the model |
| Tilt servo clear of the tray's sweep | tray is 90mm wide, tilts about y | servo starts at y=48.5 |
| Yoke's bearing above the servo's top face | servo's top steps up to 14.5mm | bearing at 15.5mm |
| Thumbscrew reaching a 4.5mm bin wall | 13.6mm of travel | M3 x 16 gives 2.4mm spare, M3 x 20 gives 6.4mm |
| Pipe lock thread engagement | enough for an M3 insert, about 4mm | 6.2mm |
| Screw into the bracket feet | must not bottom out in 9mm | M3 x 8 |

The first two are Fusion's own interference analysis, run on the assembled
model and then re-run at 13 tilt angles from -65 to +65 degrees, rather than
checked by eye.

### The five overlaps, and why they are there

Re-run on 11 August over all sixteen parts, the check reports five overlaps, and
**every one of them is a printed part against reference geometry, not against
another printed part**:

| Between | Overlap |
| :--- | ---: |
| Each of the three conduits and its clamp | 314.2 mm3 |
| Each of the bin's two long walls and its clamp | 157.0 mm3 |

These are seating overlaps in the assembly's placement rather than faults in the
parts: a conduit pushed 1mm past its socket's end stop, a clamp rib pressed
about 1.75mm into a wall. **The conduit seating is still worth a look**, because
the leg lengths are measured from those sockets and 1mm of it is unaccounted
for.

Two overlaps that were here earlier are gone, and both were the crash rather
than the design. The pan servo was 1235.1 mm3 inside the **rolled-back 11mm hub
plate**, which had no slot for it to drop through; the plate has since been
rebuilt to the committed 4mm one. A further 38.1 mm3 between the servo and the
tilt yoke went with the yoke's own repair. Both are in
[build_log.md](build_log.md).

---

## Bought parts

- **2 x MG996R servos**, 40.7 x 19.7 x 42.9mm. The pan one is clamped by the
  pan ring, the tilt one bolts to the yoke.
- A **pan-tilt tracker** was bought and built, and is no longer used. Its
  `Tracker.step` is what made the replacement possible: with only the STL it had
  to be treated as fixed.
- **20mm PVC electrical conduit**, cheap, light and far stiffer than needed for
  roughly 1kg. Cut to length per bin; this is the only thing that changes
  between bins.
- **Three bin bags and a handful of bulldog clips**, which are the three
  compartments. Nothing is printed or cut for these.

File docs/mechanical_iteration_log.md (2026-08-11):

# VCE Systems Engineering: Mechanical Iteration Log

*This document records the iterative design of the sorting mechanism. The
finished design is described in [mechanical_design.md](mechanical_design.md).
The iteration history of the AI subsystem lives in the portfolio deck
(`portfolio/ai_bin.js`), not here.*

Every fault below was found before anything was printed, by checking the model
against calculated geometry rather than by eye. The method is described at the
end.

---

## Summary of faults found and corrected

| # | Fault | Consequence if built | Fixed by |
| :---: | :--- | :--- | :--- |
| 1 | Tray mounting boss stood 1mm proud of the saddle | Tray could not be bolted on at all | Boss capped by the tray's own surface |
| 2 | Pipe lock screw had 1.56mm of thread | Strips on assembly, leg pulls out | Screw moved to a pad on top, 6.2mm |
| 3 | Hardware list called for M3 x 12 into a 9mm foot | Screw bottoms out, joint never tightens | Corrected to M3 x 8, lengths now calculated |
| 4 | Thumbscrew length overstated by 3mm | Buying M3 x 25 that was never needed | Calculation corrected for the rib radius |
| 5 | Retaining tabs 0.25mm too tight for the real base | Pan-tilt will not drop into the plate | Bore opened from 124.5 to 125.6mm |
| 6 | Tray spacer could not bolt to the tilt arm | Tray cannot be attached | Replaced with a socketed mount |
| 7 | Spacer 15mm tall for clearance it did not need | Head taller and less stiff than necessary | Reduced to a 6mm plate after measuring |
| 8 | Mount plate offset 6.5mm from the tray boss | Looks like a mistake, boss unsupported | Plate resized to contain both footprints |
| 9 | Pan ring screws at R=44 broke into the bracket screw holes at R=42 | Screw wanders into the neighbouring hole, neither joint pulls up | Moved to R=50, clear of both existing hole circles |
| 10 | Servo's top face is a stepped stack 2.3mm proud of its case | Ring and yoke both sat on it; head would not seat flat | Bearing raised to 15.5mm, 1mm clear of the highest step |
| 11 | 1mm rib down the centre of the servo flange | Flange rocks on the rib instead of clamping | 3mm relief groove in the ring's pocket ceiling |
| 12 | Tilt servo's flange fouled the yoke's rib | Servo cannot drop into its tower | Servo moved 1.5mm outboard, rib notched 2.1mm |
| 13 | Camera head's bolt recess cut into the top face | Webcam hangs under the arm upside down | Recess moved to the underside, thread now points up |
| 14 | Lightening the sockets opened the camera post bore to the air | Post has no lid and no end stop, so the camera aim is unset | Bottom corners kept where anything is attached below |
| 15 | Box hanger's thumbscrew entered the face the box hangs on | Screw head trapped behind the box, which then cannot sit flat | Rib and screw swapped ends, screw now enters from inside the bin |

---

## Iteration 1: the tripod hub

### Implementation
A printed plate carrying three PVC legs to three rim clamps, replacing the
original plan of a laser-cut top plate sized to one specific bin.

### Evaluation
Good. Bin size becomes a pipe length rather than a new part, and the line-plus-
point clamp grips a rectangular bin, a round bin or a box without adjustment.
Two problems surfaced later and are recorded below as faults 2 and 5.

---

## Iteration 2: the sorting tray

### Implementation
First attempt was a curved tray with a rim. Rejected on reasoning before
modelling: a rim traps the item exactly when the tray is trying to tip it out.

Second attempt, and the current design, is a rimless saddle: sides curl up 10mm
to roll the item back to the middle, ends curl down 5mm so it leaves cleanly.

### Evaluation
The 5mm end drop was chosen against a calculated limit, not picked. It gives a
steepest slope of 9.5 degrees, comfortably under the roughly 19 degrees at which
plastic slides on PLA, so the item stays put until the tray is tipped.

---

## Iteration 3: the pipe sockets went from blocks to shells

### Implementation
Every part that holds a pipe (three leg brackets, two bin clamps, one camera
clamp) did it with a round bore through a solid block. The block was 663 mm2 in
section around a 343 mm2 bore, so 36% plastic and 64% air, and the plastic was
in the wrong place: **1.49mm of wall at the equator and 6mm in the corners.**

The outer face was replaced by the bore's own profile offset 2.5mm, with 45
degree flanks so it still prints without support. Cut as a subtraction from the
old outline, so the part can only shrink and no clearance in the assembly can
change.

### Evaluation
Sound, and cheaper than it looks. The four corners were not on any load path:
the section is nowhere thinner than the 1.49mm it already had, and the socket is
now a constant-section tube instead of a block with a hole in it.

| | Before | After | |
| :--- | ---: | ---: | ---: |
| Bin clamp, x2 | 17,478 mm3 | 13,709 mm3 | -21.6% |
| Camera clamp | 30,919 mm3 | 23,649 mm3 | -23.5% |
| Leg bracket, x3 | 16,137 mm3 | 14,657 mm3 | -9.2% |
| **All six** | **114.3 cm3** | **95.0 cm3** | **-16.8%** |

Two things were checked rather than assumed. The pipe lock screw still gets the
**6.2000mm** of thread engagement that fault 2 was raised to fix, measured by
binary search onto the two faces, because the full 10mm pad seat was deliberately
kept when everything around it was cut away. And the minimum wall is **1.50mm**,
the same figure as before, so nothing got thinner.

The saving in real filament will be smaller than 16.8%. These figures are solid
volume, and the corners that went were partly infill, not solid plastic. What
went is mostly the cheapest material in the part.

**The camera clamp is only 23.5% and the bracket only 9.2% because of fault 14
below**, which is the more interesting half of this iteration.

---

## Fault 14: cutting the corners opened the camera post socket

**Found** on inspection of the changed part, before it went any further.

**Cause.** The rule "the corners are doing nothing" was applied to all four
corners of all six parts without asking what was underneath each one. On the
camera clamp there is something underneath: the post socket. The block's bottom
face is that socket's lid, and the seat the post's end butts against.

**Consequence.** Narrowing the block's underside to a 9mm strip left the 20.46mm
post bore **open to the outside air** on both sides. Probed across the bore, the
column at y=9 and y=10 was air the whole way through. The post would also have
lost its end stop, so nothing would set how far it went in, which sets where the
camera points.

**Fix.** The bottom corners are kept on the camera clamp and on the leg bracket,
where the block lands on the foot and the tube walls, 25mm apart, have to reach
it. They are cut only on the bin clamp, where nothing is underneath. That costs
1,930 mm3 on the camera clamp and 2,289 mm3 on each bracket, and it is the whole
reason those two parts save so much less than the bin clamp.

**What it changes about the method.** Volume is a bad guide to what is load
bearing. The corner material on the bin clamp and the corner material on the
camera clamp measure the same and do completely different jobs. The check that
caught it was a containment probe across the bore, not a look at the number.

---

## Iteration 4: somewhere for the electronics to live

### Implementation
A box hanging on the outside of the bin rim, on a separate hanger that stays
with the bin when the box is lifted off. Three positions were considered and the
reasoning for the one chosen is in
[mechanical_design.md](mechanical_design.md).

The box was drawn as **one** part first, with the rim hook built into its back
wall. That was rejected on printing rather than on strength. An open-topped box
prints open side up with every wall vertical; a hook over the rim opens
downward, so its inner leg would have started in mid air and needed support
material through the slot the whole fit depends on. Splitting it lets the box
print open side up and the hanger print standing, where the slot's flat roof is
a 15mm bridge between two legs rather than an overhang.

### Evaluation
The split cost 18.1 cm3 for a second part and paid for it three times: the slot
prints clean, the box lifts off without disturbing the jaw's setting, and the
thumbscrew stays reachable, which fault 15 below turned out to depend on.

The box is the largest part in the project at 62.0 cm3, against 30.9 for the
tray and 28.3 for the hub plate. Cutting the walls to a frame took it from 85.2
to 62.0 cm3, which is 27%, and vents the Pi at the same time. That is the same
argument as iteration 3: a box is a shape you get by extruding a rectangle, and
most of what it encloses is doing no work.

One number is an assumption rather than a measurement. The inside is 185mm long
because a Pi 3B at 85mm and a **half-size** 83mm breadboard have to lie side by
side, and the breadboard was sized off the prototype photograph, not with
calipers. A full-size 165mm board would not fit and the box would have to grow
to 270mm, which would no longer clear the leg clamps on that wall.

---

## Fault 15: the thumbscrew was on the face the box hangs on

**Found** while working out the order the parts go together, before the hanger
was exported.

**Cause.** The hanger began as a copy of the bin clamp, which puts its rounded
rib inside the bin and takes its thumbscrew from the outside. On the clamp
nothing is ever attached to that outer face. On the hanger, that outer face is
precisely what the box hangs against.

**Consequence.** The screw head would have been sandwiched between the hanger
and the box's back wall. The box would have sat 3 to 5mm proud and rocked on the
screw head, and the screw could not have been reached at all without lifting the
box off first.

**Fix.** The rib moved to the outer leg and the screw now enters through the
inner leg, from inside the bin. The outer face is left flat, which is what the
box needs, and the screw is set once before the bags go in.

**What it changes about the method.** Copying a proven detail carries its
assumptions with it. The clamp's screw direction was free because nothing was
ever bolted to that face; the hanger's is not. Nothing about the clamp says so,
because on the clamp it never mattered.

---

## Fault 1: the mounting boss stood proud of the tray

**Found by** counting horizontal facets in the exported mesh. 318 of them sat at
exactly z = +1.0mm, which should not exist on a curved surface.

**Cause.** The boss was a plain prism running from 6mm below the shell to 1mm
above the origin. The saddle's surface at its centre is at zero, so the boss
finished 1mm above the face.

**Consequence.** Two, and the second is fatal:

1. A flat plateau in the middle of the sorting surface, exactly where the item
   lands and the camera looks.
2. The countersinks ended inside that plateau. Above them the hole was only
   3.4mm wide, and an M3 countersunk head is 6mm. **The tray could not be
   fastened to the tilt plate at all.**

**Fix.** The boss is now intersected with a copy of the tray's own top surface,
so it cannot break through whatever the parameters are changed to. The
countersink cone was also lengthened from 1.8 to 6mm, because on a curved
surface a cone that stops at a fixed height leaves a lip on the high side.

Tray volume dropped from 32,362 to 30,925 mm3, which is the protruding material
removed.

---

## Fault 2: the pipe lock had 1.56mm of thread

**Found by** calculating thread engagement at every threaded hole while checking
whether brass inserts would fit.

**Cause.** The screw entered from the side, and the bore is at its widest exactly
where the block's taper has pulled the wall in. That leaves 1.56mm of plastic:
about three threads of M3, self-tapped into PLA, holding a leg on.

**Consequence.** It strips if you lean on the screwdriver, and there is nowhere
near enough material for an insert.

**Fix.** The screw now enters through the block's flat top, through a 10mm pad,
giving 6.2mm of thread and room for a brass insert with 2.9mm of plastic around
it. The pad sits on a horizontal face, so the part still prints with no support.

---

## Fault 3 and 4: the hardware list drifted from the geometry

The list of screws was written by hand and stopped matching the model.

**Fault 3.** It called for M3 x 12 into the bracket feet. With an insert there is
only 9mm of depth, so a 12 would bottom out and never pull the joint tight. It
wants an 8. The pipe locks and tab screws were over-specified the same way.

**Fault 4.** The thumbscrew calculation measured the jaw gap from the centre of
the rib instead of its surface, overstating every thumbscrew by one 3mm rib
radius. That is what made the design ask for an M3 x 25 it never needed.

**Verified** by casting a ray down the screw axis through the exported mesh:
clear opening 13.124mm, screw touches a 4.5mm wall at 13.624mm. An M3 x 16 has
2.4mm of travel left.

**Fix.** The model now calculates and prints every screw length when it renders,
so the list cannot drift again.

---

## Fault 5: the retaining tabs were too tight for the real pan-tilt

**Found** when the supplied pan-tilt STEP was placed in the assembly. Its base
measures 125.00mm exactly. The plate had been cut for 124.5, measured off the
real part with calipers.

**Consequence.** The tabs sat 0.25mm inside the base on every side. The pan-tilt
would not have dropped into the plate, and this is not something you discover
until both parts are printed and in your hands.

**Fix.** Bore opened to 125.6mm, giving 0.3mm a side to seat. The plate grew to
132mm and the bracket feet moved out with it; the pipes came down to 103.73 /
118.00 / 103.73mm.

---

## Fault 6 and 7: the tray spacer

**Fault 6.** The spacer was a plain 43 x 26 x 15mm block with four holes on a
32 x 15 pattern, inherited from a bracket that is no longer being used. The tilt
arm offers **two** M3 holes 15mm apart on a 19 x 34mm face. Nothing lined up, so
the tray could not be attached. Two screws in a line would also have let the
tray rock.

**Fault 7.** The spacer was 15mm tall to clear the pan bracket at full tilt, a
figure chosen by guess. Sweeping the tray around the tilt axis against the
bracket shows the underside needs to be 27.2mm above that axis at any angle, and
the arm's top face is already 37mm up. The height was solving a problem that did
not exist.

**Fix.** A socketed mount replaces it. The socket drops over the end of the arm,
so the arm resists twisting rather than the screws. The top plate carries the
tray's four holes and, being wider than the arm, moves the tray back over the
pan axis, which sits 6.5mm away from the arm's mounting face. The plate is 6mm
instead of 15, so the head is lower and stiffer.

---

## Fault 8: the mount plate looked crooked

**Found** visually, in a render from underneath, and confirmed by measurement.

**Cause.** The plate was centred on the tilt arm and the tray's boss is centred
on the pan axis. Those are 6.5mm apart, so the two rectangles sat offset. All
four bolts were inside both, so it would have worked, but it read as an error.

**Fix.** The plate is now 52 x 45, sized to contain both footprints. Its 52mm
width is the tray boss exactly, so those edges line up on purpose. The offset
itself cannot be designed away, because the arm genuinely sits off the pan axis.

---

## Fault 13: the camera head's bolt recess was on the wrong face

**Found by** probing the solid down the bolt axis rather than looking at it. The
head is modelled with the pipe socket growing upward off its plate, then flipped
in the assembly so the socket drops over the post. The bolt recess was cut from
the same face the sketch sits on, which the flip turns into the arm's **top**.

**Cause.** Both cuts start 1mm above that sketch plane: the 6.6mm clearance hole
runs 10mm and goes clean through the 8mm arm, and the 11.5mm recess runs 5mm and
so stopped 4mm in. Correct depth, wrong end.

**Consequence.** The hex head would sit in a recess on top and the thread would
point **down**. A webcam has its tripod socket underneath, so it would have hung
below the arm inverted, and every frame would arrive rotated 180 degrees.

**Fix.** The recess now starts 4mm along instead of 1mm back, so the same 4mm
pocket opens on the underside and the thread comes up out of the top face at
z=238. Nothing else about the part changes.

**Why the usual checks missed it.** The part was verified on volume, and volume
cannot see this: moving a pocket from one end of a hole to the other removes
exactly the same 4mm of plastic. It measured 18806.1 mm3 before and after, the
same figure that was quoted as 0.000% off the calculation. Volume proves how
much material is gone, never where from.

---

## How the parts were checked

No part was accepted on appearance. Each was verified against geometry
calculated independently of the model:

- **Volume and bounding box** compared against figures worked out by hand from
  the design dimensions. Every part agrees to better than 0.03%, and two errors
  were caught this way: a hole that only drilled halfway through the bracket,
  and a profile 0.06% undersized.
- **Watertightness.** Every exported mesh is checked to be a closed manifold
  solid, which is what a slicer needs and what CAD needs to convert it.
- **Ray casting** through the mesh to measure real openings, which is how the
  thumbscrew error was caught.
- **Facet analysis** to find surfaces that should not exist, which is how the
  tray boss was caught.
- **Swept clearance** of the tray against the pan bracket through the full tilt
  range, which is how the spacer height was settled.

The limitation is that all of this validates the model against its own intent.
It cannot catch a wrong measurement of a bought part, which is exactly how fault
5 arose and why it was only found when the real pan-tilt model arrived.

---

## Toolchain notes

Three problems cost real time and are worth recording.

**Fusion can report a save it has not done.** This is the most expensive one,
because it is what destroyed the hub plate's feature history. Editing a part and
saving it appeared to work: `Document.save()` returned true, the document then
reported itself unmodified, and it reported itself as its own latest version.
The data panel still held the old version, and the edit existed only in memory.

It happens when the document being edited is the copy Fusion opens **as a
reference inside the assembly** rather than the file opened on its own. Two
handles on one file are open at once, and the reference copy will not commit.

Two habits come out of it, and both are cheap:

- Open a part by its file id, edit that, and never edit the copy that came in
  under an assembly.
- **Check the version number in the data panel after saving.** The return value
  of the save, and the document's own "am I modified" flag, both lie.

The same failure would have been caught much earlier if anything had compared
the model against the committed export, which is now how every part here is
checked.

**OpenSCAD to STEP.** The hub was developed in OpenSCAD, which only exports
meshes. Converting to solid CAD via FreeCAD failed on two constructs: `hull()`,
and 2D boolean operations inside `linear_extrude()`. Both were rewritten to draw
the same shapes directly, geometry-neutral to within 0.0003%, after which all
parts converted. The parts have since been rebuilt natively in Fusion, which
removes the need for this conversion entirely.

**Fusion assembly positions.** Moving a component in a parametric assembly is a
position change, and Fusion discards those on the next rebuild unless they are
captured as a snapshot. An entire session of repositioning silently reverted
before this was understood.

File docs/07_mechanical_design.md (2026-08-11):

# Mechanical Design

*How the sorting mechanism works and why it is shaped the way it is. The
iteration history behind these decisions is in [08_mechanical_iteration_log.md](08_mechanical_iteration_log.md).*

---

## The problem

Sort an item into one of three compartments of an ordinary wheelie-style bin,
without modifying the bin, using two servos.

## The solution in one line

A printed tripod clamps across the bin's rim and carries a pan-tilt head. The
item lands on a tray, the head turns to face a compartment, the tray tips, and
the item free-falls in.

---

## 1. The tripod hub

Three lengths of 20mm PVC electrical conduit radiate from a printed plate to
three clamps that grip the bin rim.

**The legs are structure, not chutes.** Rubbish never goes through them. It tips
off the tray and falls past them. This is what keeps the mechanism small: the
only thing that has to be printer-sized is the hub, and the span is a pipe you
cut to length.

**Bin size is a pipe length.** Changing bins means cutting three new pipes, not
reprinting anything. For the 60L ecobin the three legs come out at 103.73,
118.00 and 103.73mm, and the fact that they differ is exactly the point: three
legs at 120 degrees cannot reach the walls of a rectangle at equal distances.

### Why the legs sit at 60, 180 and 300 degrees

The drops go at 0, 120 and 240, midway between the legs. If they lined up, the
tray would fling items straight into a leg. The three bin dividers go directly
under the three legs, so each sector is a clean opening.

### Why the clamp is shaped oddly

Three legs at 120 degrees cannot all meet a rectangular bin's walls square on.
On the ecobin one leg is square to its wall and the other two are 30 degrees
off.

So the fixed jaw is a **vertical rounded rib**, which touches the wall along a
line, and the thumbscrew pushes a **single point** at it from the other side. A
line plus a point pinches at any angle. The same clamp therefore grips a
rectangular bin, a round bin or a cardboard box, with no adjustment.

The outer post is deliberately narrow at 9mm. A wall arriving at an angle sweeps
sideways across the jaw, and a wide outer plate would foul it before it seated.

### Printing without supports

Every pipe socket bore is a **truncated teardrop**, not a circle: a flat-topped
45 degree peak over a round bore. That is what lets a sideways hole print with
no support. A round pipe still slides in.

---

## 2. The tray

A shallow saddle, 120 x 90mm, 3mm shell. Mathematically a hyperbolic paraboloid:

```
z = 10 * (y/45)^2  -  5 * (x/60)^2
```

**No rim anywhere.** A rim would trap the item exactly when you are trying to tip
it out, which is the opposite of the job. The surface runs out to a thin edge.

| Direction | Shape | Why |
| :--- | :--- | :--- |
| Across (the tilt axis) | curls **up** 10mm | When the head pans, the item is thrown sideways. This gentle valley rolls it back to the middle. It is the only retention there is, and it works with gravity rather than blocking anything |
| Along (the dump direction) | curls **down** 5mm | Where the item leaves. Curling down means there is nothing to climb, so it goes as soon as it tips |

**Why 5mm and not more.** At 5mm the steepest slope is 9.5 degrees, well under
the roughly 19 degrees at which plastic starts sliding on PLA. So the item stays
put until the tray is actually tipped. Past about 8mm you are relying on luck.

Print it matte white or grey. The camera classifies the item against this
surface, so a busy or shiny background costs accuracy.

---

## 3. The tray mount

The tray does not bolt to the tilt arm directly. The arm presents a 19 x 34mm
face with two M3 holes 15mm apart; the tray wants four holes on a 32 x 15
pattern. Nothing lines up, and two screws in a line would let the tray rock.

The mount is a **cap**. Its socket drops over the end of the arm, so the arm
itself resists twisting rather than the screws having to. The top plate carries
the tray's four holes.

**It also recentres the tray.** The tracker's pan axis sits 10mm off its own base
centre, because the designer centred the servo body rather than its output
shaft. The plate being wider than the arm is what pulls the tray back over the
axis it actually rotates about.

Print it upside down, plate flat on the bed, and every overhang faces the bed.

---

## 4. Getting three bins out of a 180 degree servo

Tilting the tray **backward** throws the item 180 degrees opposite to where the
pan is aiming. Every pan position therefore covers two directions, and three
drops 120 degrees apart need only 120 degrees of pan:

| Drop | Pan | Tilt |
| :--- | :--- | :--- |
| 0 deg | 0 | forward |
| 120 deg | 120 | forward |
| 240 deg | 60 | backward |

Without this the mechanism would need 240 degrees of pan and a servo upgrade.

---

## Verified clearances

These were measured against the assembled model rather than estimated.

| Check | Requirement | Actual |
| :--- | :--- | :--- |
| Tray swinging past the pan bracket | underside at least 27.2mm above the tilt axis, at any tilt angle | 43mm |
| Pan-tilt base seating in the plate's tabs | tabs must clear a 125.0mm base | 125.6mm bore, 0.3mm a side |
| Thumbscrew reaching a 4.5mm bin wall | 13.6mm of travel | M3 x 16 gives 2.4mm spare, M3 x 20 gives 6.4mm |
| Pipe lock thread engagement | enough for an M3 insert, about 4mm | 6.2mm |
| Screw into the bracket feet | must not bottom out in 9mm | M3 x 8 |

---

## Bought parts

- **Pan-tilt tracker**, printed brackets supplied as `Tracker.step`. 125mm base,
  133mm tall. Its own camera mount plate is removed; the tray mount replaces it.
- **2 x MG996R servos**, 40.7 x 19.7 x 42.9mm, mounted on 49 x 10mm flange
  patterns in the stand and the tilt arm.
- **20mm PVC electrical conduit**, cheap, light and far stiffer than needed for
  roughly 1kg.

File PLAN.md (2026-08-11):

# Project Plan: AI-Powered Smart Bin (Systems Engineering 3&4)

## 1. Project Overview

- **Objective:** Develop a low-cost, AI-powered smart bin capable of automatically sorting waste into three distinct categories using a cloud Vision Language Model, with a web-based control dashboard.
- **Inspiration:** Ameru AI Bin.
- **Core Mechanism:** A rotating and tilting tray system driven by two servos to direct waste into one of the three internal partitions.
- **Constraint:** Self-funded, requiring a strict focus on low-cost, high-value components.

## 2. System Architecture

The system uses a **dual-board architecture** to separate concerns:

| Board | Role | Responsibilities |
| :--- | :--- | :--- |
| **ESP32-CAM** | Brain | Camera capture, WiFi, cloud VLM classification, web server, decision-making |
| **ESP32 DevKit** | Muscles | Servo PWM, ultrasonic sensor, real-time hardware control |

The two boards communicate over **UART serial** using a simple command protocol. This separation ensures that real-time servo timing is never disrupted by WiFi/HTTP activity on the ESP32-CAM, and the ESP32-CAM can be rebooted or updated without leaving servos in an unsafe state.

> The two-board serial protocol was dropped when the build moved to a single Raspberry Pi.

### Hardware Components (Low-Cost Focus)

- **AI Compute:** ESP32-CAM (~$12 AUD) -- Built-in 2MP OV2640 camera and WiFi. Captures images and sends them to a cloud VLM for classification. No local AI inference required.
- **Hardware Controller:** ESP32 DevKit (~$8.67 AUD) -- Dedicated microcontroller for real-time servo PWM and sensor reading. Hardware timers ensure microsecond-accurate pulse generation independent of WiFi/HTTP workload.
- **Camera:** Integrated ESP32-CAM OV2640 (2MP).
- **Actuators:** 2x MG996R High-Torque Servos (180-degree, metal gear). Provide enough torque to handle the tray and the weight of typical waste items.
- **Sensors:** 1x HC-SR04 Ultrasonic sensor to detect when an item is placed on the tray, triggering the camera and classification.
- **Lighting:** WS2812B 12-LED ring (48mm, 5V) for consistent camera illumination and visual category feedback (green = compost, blue = recycling, red = general).
- **Power:** USB-C PD trigger board (~$3.14 AUD) negotiating 5V from any USB-C PD charger. 1000uF capacitors on the servo power rail to absorb stall current spikes.
- **Structure:** Repurposed standard 60L bin with a laser-cut MDF/acrylic top plate. 3D printed pan/tilt bracket (MakerWorld model 973248, adapted for MG996R).

> Current bill of materials and budget: the Parts List & Budget slide in `portfolio/ai_bin.js`.

### Software Stack

- **ESP32-CAM (Arduino):**
  - **Camera:** ESP32 camera library for JPEG capture.
  - **WiFi/HTTP:** Sends captured image to cloud VLM API, receives JSON classification.
  - **Web Server:** Hosts the control dashboard over WiFi.
  - **Serial Comms:** UART commands to the ESP32 DevKit.

- **ESP32 DevKit (Arduino):**
  - **Servo Control:** Hardware PWM for precise pan/tilt actuation.
  - **Sensor Reading:** HC-SR04 ultrasonic with hardware timer interrupts and software debounce.
  - **Serial Comms:** UART listener for commands from ESP32-CAM, acknowledgement responses.
  - **Failsafe:** Watchdog timer returns servos to home position if no heartbeat from ESP32-CAM within 5 seconds.

## 3. Mechanism Design: Rotate & Tilt

The sorting mechanism operates on a two-axis system:

1. **The Tray:** The central landing zone for waste.
2. **Servo 1 (Pan/Rotate):** Mounted vertically. It rotates the entire tray assembly to align the dropping edge with one of the three partitions (e.g., General, Recycling, Compost).
3. **Servo 2 (Tilt):** Mounted horizontally on the rotating assembly. It tilts the tray downwards to let gravity slide the item into the selected partition.

### Structural Design: Top Frame Method

To handle the bin bags cleanly without them interfering with the central servos:

- **Base Bin:** A single large 60L-75L rectangular container (Willow Dome Bin from Bunnings).
- **Top Plate:** A laser-cut piece of acrylic or 4mm MDF mounted across the top of the bin.
- **Drop Zones:** The top plate features three distinct cutouts/holes corresponding to General, Recycling, and Compost.
- **Bag Management:** Individual bin bags are pushed through each hole, folded back over the lip of the wood/acrylic, and secured tightly using bulldog/binder clips.
- **Mechanism Mounting:** The 3D printed servo pan/tilt bracket is mounted securely to the centre of this top plate.
- **Camera Arch:** A laser-cut arch extends above the tray, holding the ESP32-CAM and WS2812B LED ring at the correct height for consistent image capture.
- **Emptying:** The entire top plate lifts off, providing clear access to tie and remove the bags.

## 4. AI Classification: Cloud VLM

The ESP32-CAM captures an image and sends it to a cloud-hosted Vision Language Model for classification:

- **How it works:** The ESP32-CAM captures a JPEG, encodes it, and POSTs it to a VLM API endpoint (e.g., GPT-4o, Gemini, Llama Vision via OpenRouter). The VLM returns a JSON response with the waste category, item label, and confidence score.
- **Providers:** Multiple VLM providers are supported and configurable via the web dashboard (OpenRouter, OpenAI, Google Gemini, Ollama for local testing, or any OpenAI-compatible custom endpoint).
- **Latency:** ~1-2 seconds per classification (network dependent). Acceptable given the mechanical sort cycle adds ~0.7-1s, keeping the total under the <3s parameter target.
- **No training required:** Cloud VLMs are pre-trained and classify any everyday object out of the box.
- **Trade-off:** Requires WiFi connectivity. The system is designed for fixed indoor locations (schools, offices) where WiFi is reliably available.

> Design iteration history: the Design Iteration slides in `portfolio/ai_bin.js`.

## 5. Web Dashboard

The ESP32-CAM hosts a lightweight web server accessible from any device on the same network. The dashboard provides:

| Feature | Description |
| :--- | :--- |
| **Live Stats** | Items sorted, category breakdown (pie/bar chart), accuracy tracking over time |
| **Camera Feed** | Live or last-frame view with classification results |
| **System Health** | Uptime, inference latency, connectivity status |
| **Manual Controls** | Servo calibration sliders, manual sort trigger, home position reset |
| **LLM Settings** | Provider selection (OpenRouter/OpenAI/Gemini/Ollama/Custom), model ID, API key management |
| **Dataset Collection** | Save captured images for accuracy auditing, export as ZIP |
| **Model Comparison** | Run two VLM providers side-by-side on the same image |

### Technical Implementation
- **Backend:** Flask running on the ESP32-CAM (or on a PC in mock/development mode), serving a REST API.
- **Frontend:** Alpine.js for reactivity + Tailwind CSS for styling (both loaded via CDN -- zero build step). Uses Server-Sent Events (SSE) for real-time stats updates.
- **Data Persistence:** SQLite database for sorting history and statistics.
- **Access:** Available at `http://<esp32-cam-ip>:8080` on the local network. No authentication required for MVP (local network only).

## 6. Project Phases & Timeline

### Phase 1: Research & Procurement
- Finalise hardware selection based on current market prices.
- Order all electronic components from AliExpress.
- Source the base bin and structural materials locally.

### Phase 2: Mechanical Prototyping
- 3D print the pan/tilt bracket (MakerWorld model 973248).
- Design and laser-cut the top plate with three partition cutouts and camera arch.
- Test servo torque to ensure the MG996R can handle the tray with a heavy item.

### Phase 3: ESP32 Firmware
- Implement the UART serial protocol listener on the ESP32 DevKit.
- Write servo PWM control with configurable angles per waste category.
- Implement HC-SR04 sensor reading with debounce and interrupt-driven triggering.
- Add watchdog failsafe (home servos if ESP32-CAM heartbeat lost).

### Phase 4: ESP32-CAM Software
- Set up camera capture and WiFi connectivity.
- Implement cloud VLM API integration (HTTP POST with JPEG image, JSON response parsing).
- Implement UART communication to send sort commands to the ESP32 DevKit.
- Add WS2812B LED ring control for illumination and category feedback.

### Phase 5: Web Dashboard
- Build the Flask backend with REST API endpoints.
- Create the frontend dashboard (stats, camera feed, controls, settings).
- Set up SQLite for sorting history persistence.
- Implement provider configuration and model comparison features.

### Phase 6: System Integration
- Connect ESP32-CAM to ESP32 DevKit over UART.
- Develop the main control loop on the ESP32-CAM:
  1. Receive item detection event from ESP32 (sensor interrupt via UART).
  2. Turn on LED ring (white illumination).
  3. Capture an image with the OV2640 camera.
  4. Send image to cloud VLM, receive classification.
  5. Set LED ring to category colour (red/blue/green).
  6. Send sort command to ESP32 with target partition angle.
  7. ESP32 executes pan -> tilt -> home sequence.
  8. Log result to SQLite and broadcast to web dashboard via SSE.
- Assemble the electronics permanently on perfboard.

### Phase 7: Testing & Refinement
- Conduct end-to-end testing with real waste (50-item test batch).
- Verify UART reliability under sustained operation (100 consecutive sorts).
- Test web dashboard responsiveness and real-time updates.
- Identify edge cases (e.g., items getting stuck, VLM misclassifications) and refine the mechanical design or adjust VLM prompts.

> Evaluated alternatives and future directions: the Evaluation & Recommendations slide in `portfolio/ai_bin.js`.

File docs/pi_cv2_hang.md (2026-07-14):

# Pi 3B — cv2 Import Hang Issue (FIXED)

## Status: FIXED ✅

**Solution:** Install `opencv-python-headless` from pip instead of the apt version.

```bash
sudo apt-get remove -y python3-opencv
pip install opencv-python-headless --break-system-packages
```

This gives you cv2 4.13.0 which imports fine on headless Pi 3B. No workarounds needed.

---

## Original Problem (for reference)

`import cv2` (OpenCV) **deadlocks the entire Python process** on the Pi 3B when using the system-installed `opencv` package (v4.10.0 via `python3-opencv` apt package).

### Symptoms
- Flask starts but produces no output, no log, doesn't bind to port
- `python3 -c "import cv2"` hangs forever
- CPU spikes to 100% on the python process
- `ps aux` shows python in `R` state but never progresses

### Root Cause
The system `opencv` package at `/usr/lib/python3/dist-packages/cv2.cpython-313-aarch64-linux-gnu.so` tries to initialize GTK/Qt display backends on import, which hangs when there's no display server running (headless Pi).

### Affected
- **Package:** `opencv` 4.10.0 (apt `python3-opencv`)
- **Python:** 3.13.5 (aarch64)
- **OS:** Debian 13 (trixie), kernel 6.12.75+rpt-rpi-v8
- **Device:** Raspberry Pi 3B, headless (no display)

### Why pip headless works
`opencv-python-headless` is built without GUI/Qt/GTK backends. It doesn't try to initialize display subsystems on import, so it works fine on headless systems.

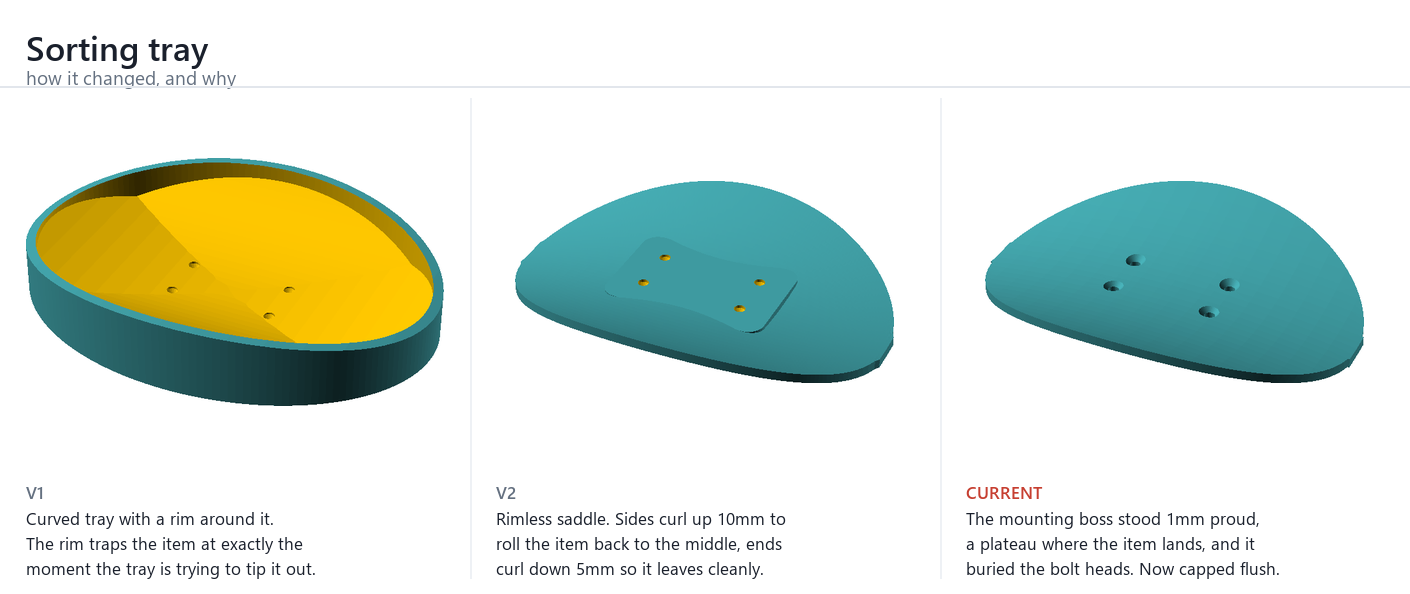
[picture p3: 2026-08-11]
portfolio/images/cad/evolution/tray.png

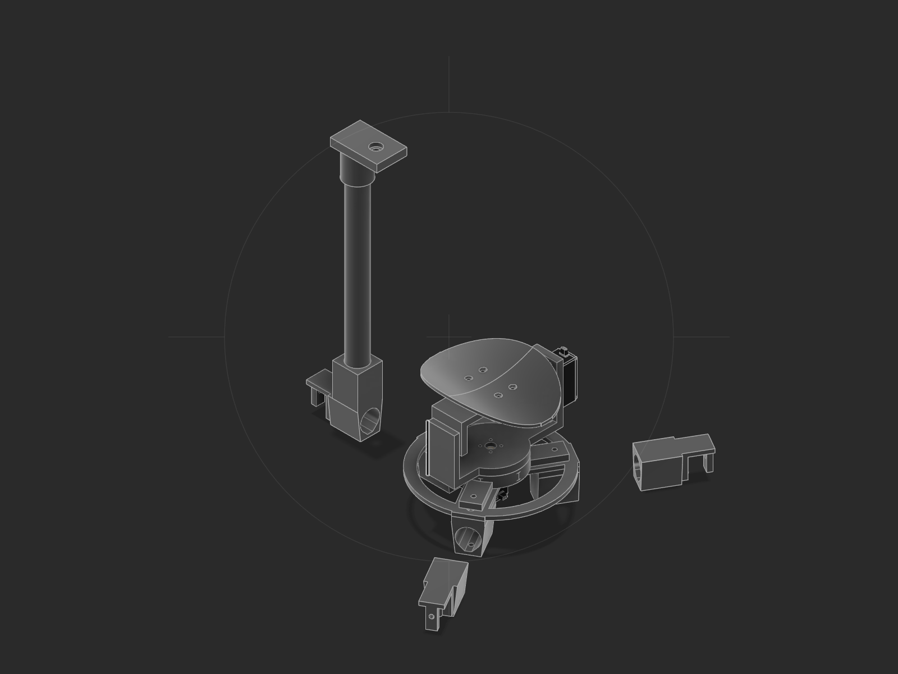
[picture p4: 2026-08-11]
portfolio/images/cad/rebuilt_head_iso.png

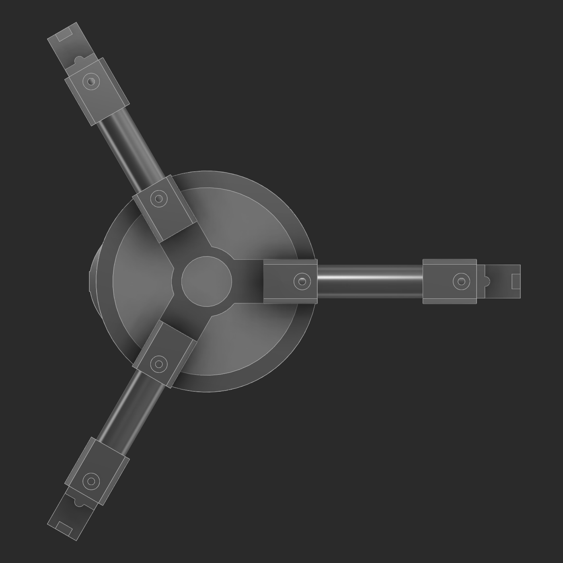
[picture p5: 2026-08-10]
portfolio/images/cad/leg_layout.png

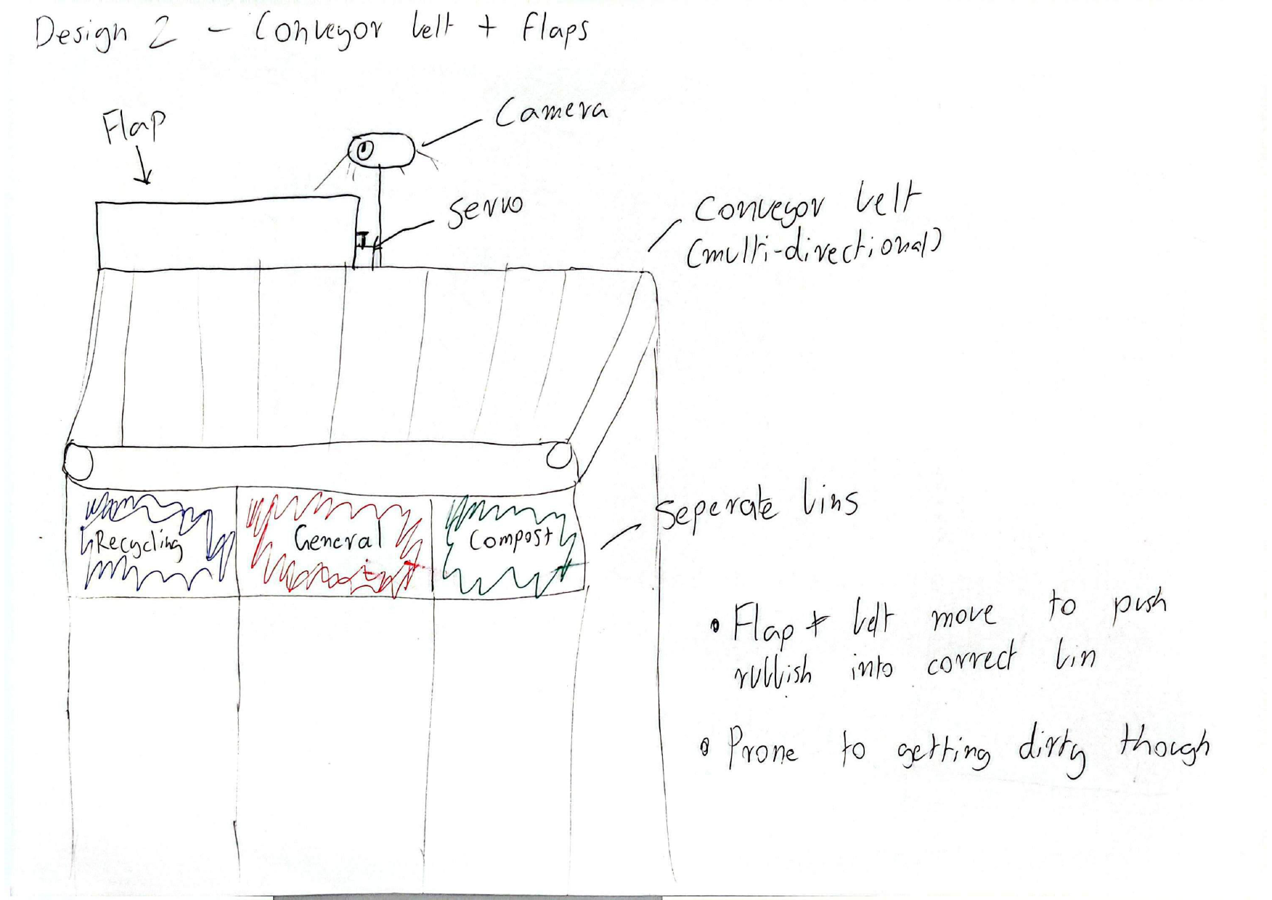
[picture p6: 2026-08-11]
portfolio/images/sketches/design_option_b.png

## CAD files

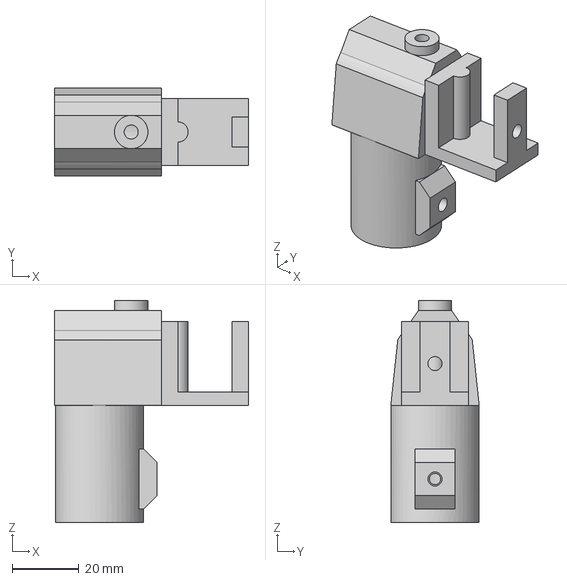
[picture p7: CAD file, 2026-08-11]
cad/step/camera_clamp.step
58.1 x 26.4 x 66.3 mm

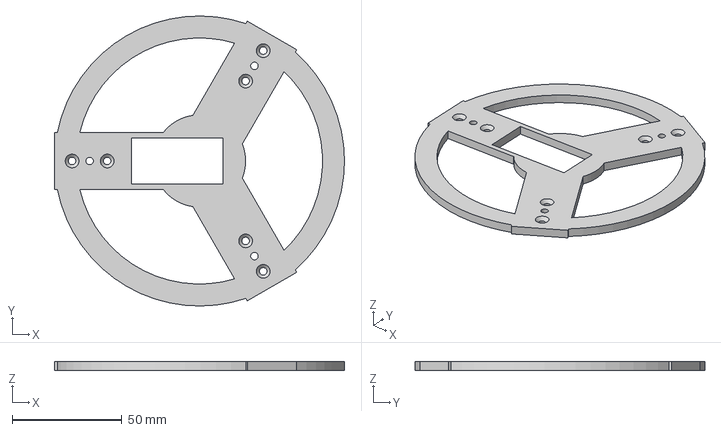
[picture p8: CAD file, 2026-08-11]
cad/step/plate.step
132.0 x 132.0 x 4.00 mm

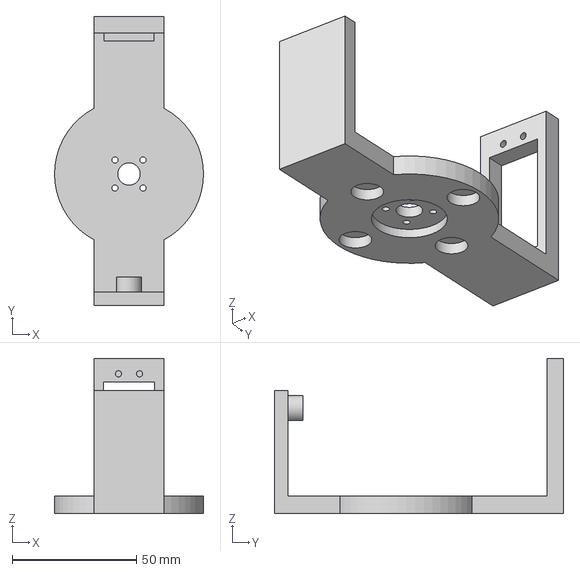
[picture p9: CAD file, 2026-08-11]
cad/step/tilt_yoke.step
60.0 x 116.5 x 62.5 mm

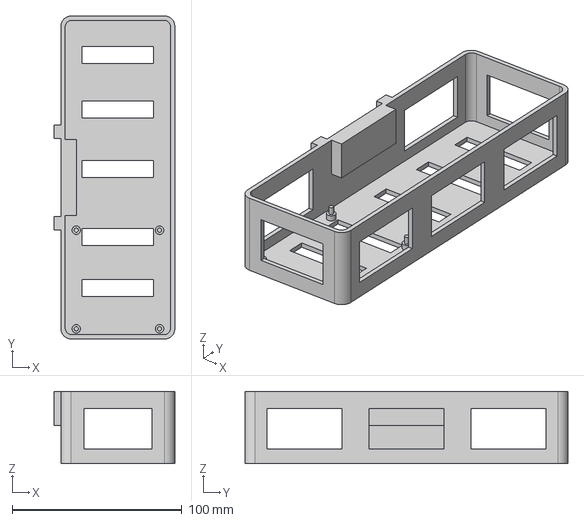
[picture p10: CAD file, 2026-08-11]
cad/step/electronics_box.step
71.0 x 190.0 x 42.5 mm

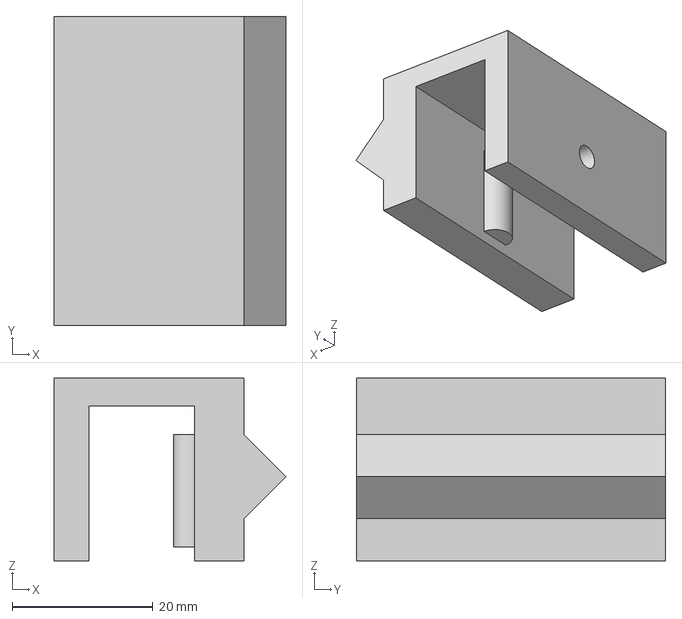
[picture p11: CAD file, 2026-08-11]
cad/step/box_hanger.step
33.0 x 44.0 x 26.0 mm

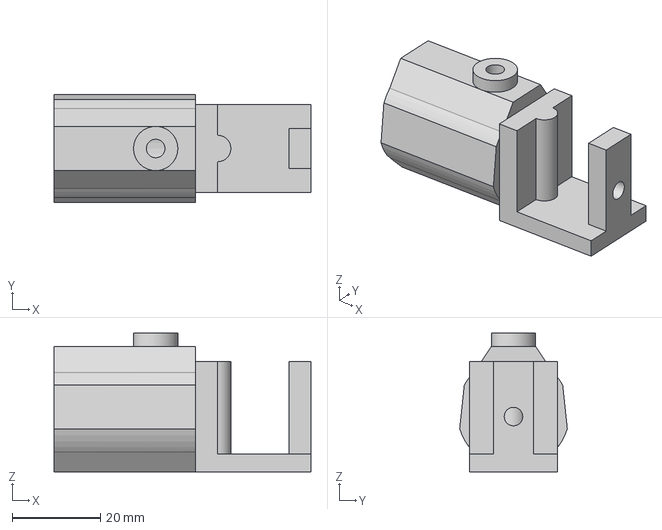
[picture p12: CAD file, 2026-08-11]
cad/step/clamp.step
58.1 x 24.4 x 31.3 mm

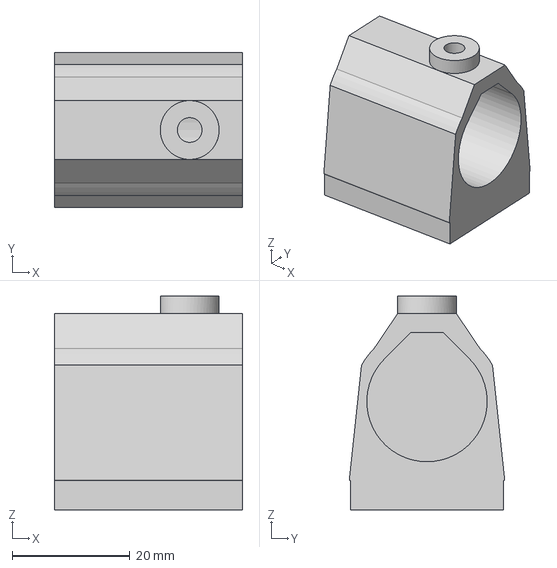
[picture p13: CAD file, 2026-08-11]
cad/step/bracket.step
32.0 x 26.4 x 36.3 mm

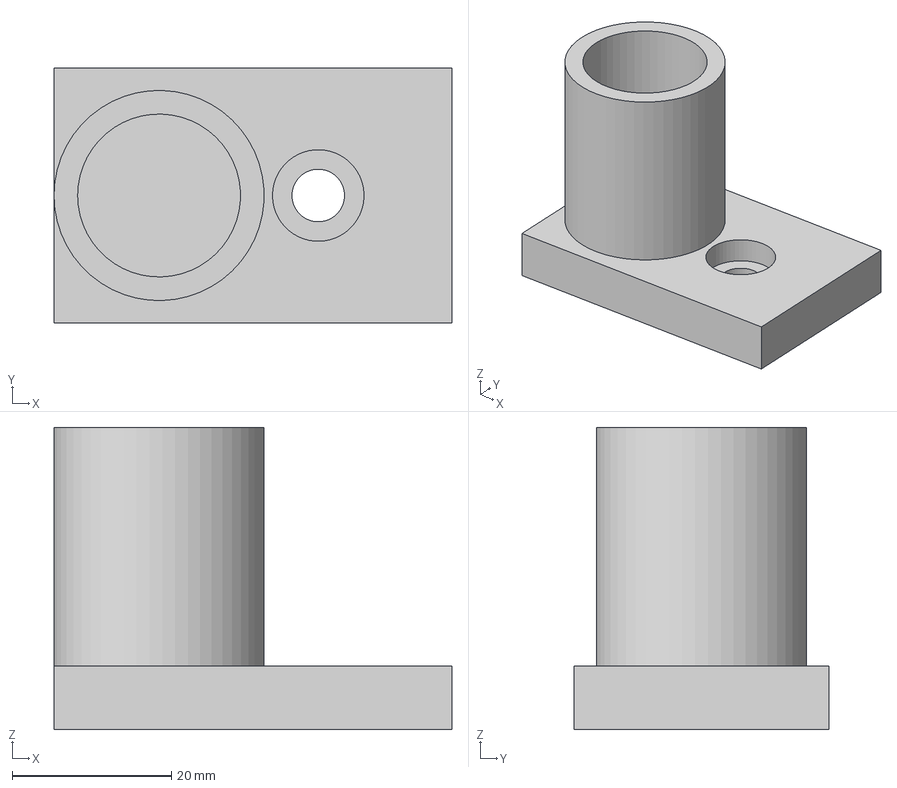
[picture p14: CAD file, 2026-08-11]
cad/step/camera_head.step
50.0 x 32.0 x 38.0 mm

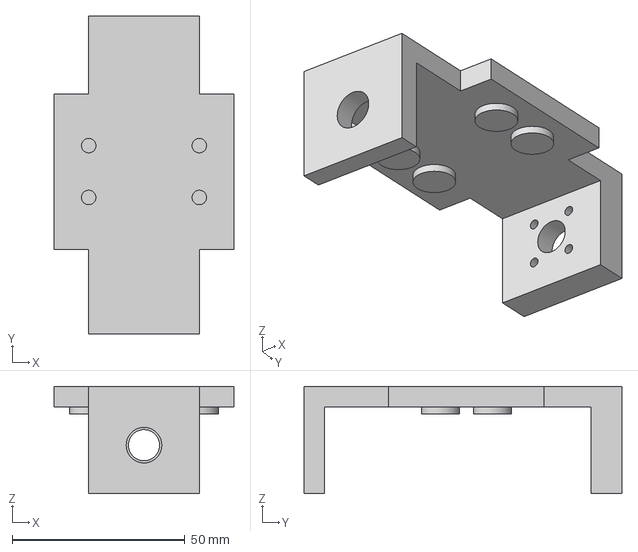
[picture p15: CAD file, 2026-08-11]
cad/step/tilt_cradle.step
52.0 x 92.0 x 31.0 mm

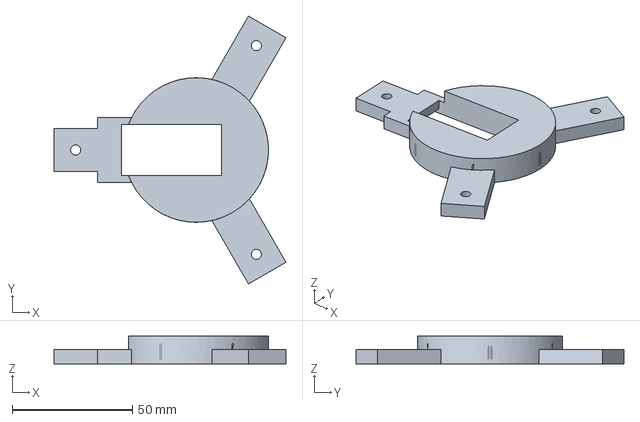
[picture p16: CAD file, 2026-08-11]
cad/step/pan_ring.step
96.3 x 111.2 x 11.5 mm

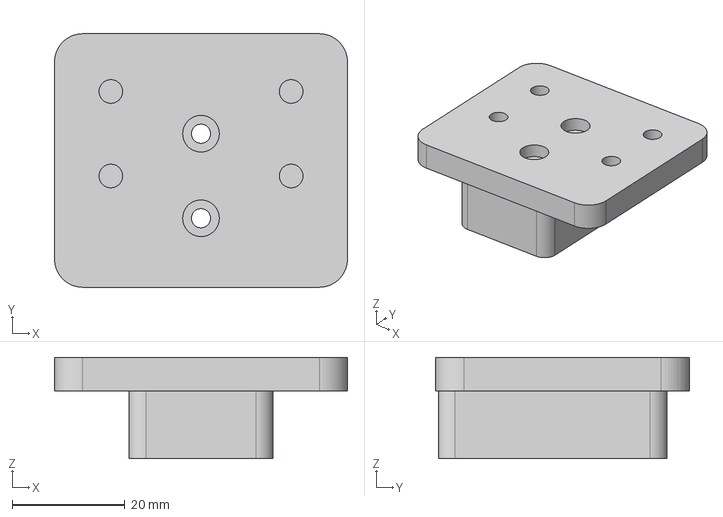
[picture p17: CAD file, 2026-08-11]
cad/step/tray_mount.step
52.0 x 45.0 x 18.0 mm

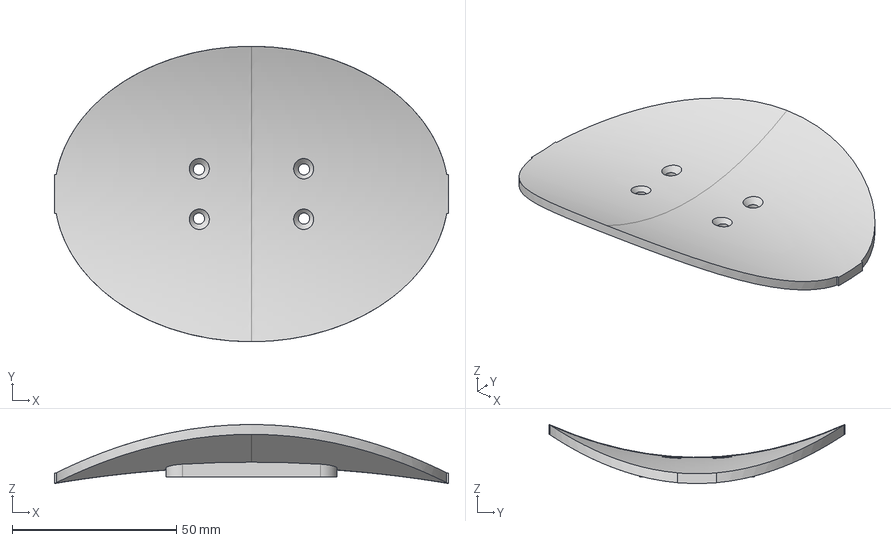
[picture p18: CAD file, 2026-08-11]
cad/step/tray.step
120.0 x 90.0 x 18.0 mm

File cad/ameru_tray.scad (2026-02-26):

/*  ═══════════════════════════════════════════════════════════════
 *  AI Smart Bin – "Ameru Style" Curved Sorting Tray
 *  ═══════════════════════════════════════════════════════════════
 *
 *  Design:
 *  - Top-down profile: Elliptical to match the bin opening but narrower
 *  - Cross-section: "Smile" curve to center the rubbish
 *  - Side profile: Tilted forward so the front lip is lower (chute) and the back is high.
 *  - Skeletonized mounting block: Hollow from below, but with a SOLID floor for the tray above it.
 */

$fn = 150; // High resolution for smooth 3D printing

// --- Parameters ---
tray_length = 170;       // Length of the tray (front-to-back, Y-axis)
tray_width = 130;        // Width of the tray (side-to-side, X-axis) - Made narrower
thickness = 4;           // Thickness of the plastic shell
smile_radius = 110;      // Radius of the horizontal curve (smaller = steeper sides)
front_tilt = 12;         // Degrees to tilt down at the front (+Y is the front chute)
riser_height = 20;       // Height of the center mounting block (acts as a spacer)

// Mounting Block (Matches MG996R aluminium bracket)
block_w = 45;
block_l = 40;
bolt_d = 3.4;            // M3 clearance hole
hole_x = 32;
hole_y = 15;
wall_t = 4;              // Thickness of the skeletonized block walls

module ameru_tray(solid_block = false) {
    difference() {
        // --------------------------------------------------------
        // 1. ADDITIVE PHASE: Create the solid outer bounds
        // --------------------------------------------------------
        union() {
            // The curved tray top
            intersection() {
                // Elliptical footprint
                scale([tray_width/tray_length, 1, 1])
                cylinder(d=tray_length, h=smile_radius + riser_height + 50);
                
                // The solid outer curve (the "smile")
                translate([0, 0, smile_radius + riser_height])
                rotate([-front_tilt, 0, 0]) // Tilt +Y side downwards
                rotate([0, 90, 0])          // Lay the cylinder horizontally
                cylinder(r=smile_radius, h=tray_width+50, center=true);
            }
            
            // The solid center mounting block below the tray
            translate([-block_w/2, -block_l/2, 0])
            cube([block_w, block_l, riser_height + 10]); // +10 so it goes up into the curved tray and merges
        }
        
        // --------------------------------------------------------
        // 2. SUBTRACTIVE PHASE: Hollow it out and drill holes
        // --------------------------------------------------------
        
        // Hollow out the curved tray (subtract the inner curved shell)
        // This creates the concave saddle shape
        translate([0, 0, smile_radius + riser_height])
        rotate([-front_tilt, 0, 0])
        rotate([0, 90, 0])
        cylinder(r=smile_radius-thickness, h=tray_width+52, center=true);
        
        // Remove the top half of the horizontal cylinder entirely 
        // (so it's an open chute, not a closed pipe)
        translate([0, 0, smile_radius + riser_height])
        rotate([-front_tilt, 0, 0])
        translate([-tray_width, -tray_length, 0])
        cube([tray_width*2, tray_length*2, smile_radius]);
        
        if (!solid_block) {
            // Skeletonize the mounting block from the BOTTOM ONLY
            // We stop hollowing it out at `riser_height - wall_t` so the tray above stays solid
            translate([-block_w/2 + wall_t, -block_l/2 + wall_t, -1])
            cube([block_w - wall_t*2, block_l - wall_t*2, riser_height - wall_t + 1]);
        }
        
        // Drill the 4 bolt holes through the entire assembly
        for(x = [-hole_x/2, hole_x/2]) {
            for(y = [-hole_y/2, hole_y/2]) {
                translate([x, y, -5])
                cylinder(d=bolt_d, h=riser_height + 50);
            }
        }
    }
}

// --- Render Selection ---
// Uncomment the version you want to view/export to STL:

// Version 1: Hollowed-out mounting block (Saves material & time, lightweight)
ameru_tray(solid_block = false);

// Version 2: Solid mounting block (Maximum strength, heavier)
// ameru_tray(solid_block = true);

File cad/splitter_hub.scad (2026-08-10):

/* ============================================================
   AI SMART BIN  -  tripod hub + bin clamps  ("the Y splitter")

   WHAT THIS IS
   A printed tripod that clamps to the rim of any bin. The
   pan-tilt bolts on top. Three lengths of PVC pipe are the legs.

   Rubbish does NOT go through the pipes. It tips off the tray
   and free-falls past them into the bin below.

   IMPORTANT - LEG POSITIONS
   The three legs sit at 60 / 180 / 300 degrees.
   Aim the tray at 0 / 120 / 240 degrees, i.e. BETWEEN the legs,
   so rubbish falls through the gaps instead of hitting a leg.
   Put the three bin dividers directly under the three legs.

   WHY THE JAW IS SHAPED ODDLY
   Three legs 120 degrees apart cannot all meet a rectangular
   bin's walls square on. For the ecobin one leg is square and
   the other two are 30 degrees off. So the fixed jaw is a
   vertical rounded rib, which touches the wall along a line,
   and the thumbscrew pushes a single point opposite it. A line
   plus a point pinches at ANY angle, so the same clamp works on
   a rectangular bin, a round bin or a cardboard box.

   WHAT TO PRINT   (all of it prints with NO SUPPORTS)
     1 x plate     flat side down, retaining tabs pointing up
     3 x bracket   foot down, exactly as it appears
     3 x clamp     as it appears, jaws pointing UP.
                   In use it is flipped so the jaws hang down.

   Every pipe bore is a truncated teardrop, not a circle. The
   flat-topped peak is what lets a sideways hole print without
   support. A round pipe still slides in.

   HARDWARE   (as set up, i.e. with use_inserts on)
     15 x M3 brass heat-set inserts
                                6 in the bracket feet, 6 in the pipe lock
                                pads, 3 in the clamp outer jaws
      6 x M3 x 8 countersunk    bracket feet, down through the plate.
                                NOT longer. Past 9mm it bottoms out in the
                                5mm foot and stops pulling the joint tight.
      6 x M3 x 8                pipe locks, down through the pads
      3 x M3 x 8 self-tapping   retain the pan-tilt base. No insert here:
                                the tabs are one wall thick, 3.2mm, and an
                                M3 insert is about 4mm long.
      3 x M3 x 16 or 20         thumbscrews, pinch the bin wall. 16 touches a
                                4.5mm wall with 2.4mm of travel left, 20 gives
                                6.4mm. bin_wall_max is what sets this.

   Render and read the console. It works the lengths out for your settings
   rather than making you trust the list above.

   PIPE LENGTH
     length = distance_from_centre_to_rim - 50
   Render the preview and read the console, it echoes the exact
   figure for whatever settings you are using.

   For the 60L ecobin (347 x 277, 4.5mm corflute) the legs reach
   169mm on the short end and 155mm on the two long sides, so cut
   to about 119, 105 and 105mm. Different lengths is exactly how
   it copes with a rectangular bin.
   ============================================================ */

PART = "preview";   // "preview" | "plate" | "bracket" | "clamp"


/* ---------- MEASURE THESE ---------- */

base_dia     = 125.6;  // pan-tilt base outside diameter, plus clearance.
                       //   The supplied Tracker.step measures 125.00 exactly.
                       //   This was 124.5, taken off the real thing with
                       //   calipers, which put the retaining tabs 0.25mm
                       //   inside the base on every side: it would not have
                       //   dropped in. 125.6 leaves 0.3mm a side to seat.
lip_h        = 7;      // height of the tabs that stop the base sliding off
bin_wall_max = 6;      // thickest bin wall the clamp must grip.
                       //   ecobin corflute is 4.5, cardboard 3-6, so 6 covers
                       //   everything this is actually going on.
                       //
                       //   This one number sets how long the thumbscrew has to
                       //   be, because the jaw gap has to clear a wall this
                       //   thick skewed as far as a rectangular bin can skew
                       //   it. It was 8, which wanted an M3 x 25. At 6 an
                       //   M3 x 20 does it with 3mm of travel spare. Raise it
                       //   for a chunkier bin and buy longer screws.

/* ---------- YOUR BIN ----------
   Outside dimensions. These do not change any printed part, they only
   work out how long to cut each pipe, and draw the bin in the preview.
   The three legs land at different distances on a rectangle, which is
   the whole reason the legs are pipes you cut rather than printed arms. */

bin_x        = 347;    // outside, long side   (60L ecobin)
bin_y        = 277;    // outside, short side
bin_t        = 4.5;    // wall thickness


/* ---------- PIPE ---------- */

pipe_od      = 20;     // PVC outside diameter. 20mm electrical conduit
                       //   is cheap, light and plenty strong for ~1kg
pipe_fit     = 0.45;   // slip fit. increase if the pipe won't push in
socket_len   = 32;     // how far the pipe goes into a socket


/* ---------- SHAPE ---------- */

wall         = 3.2;    // printed wall
plate_t      = 4;      // spoke and rim thickness
rim_w        = 10;     // width of the plate's outer rim
spoke_w      = 26;     // width of the three spokes
hub_r        = 15;     // radius of the centre hole (servo wires)
foot_t       = 5;      // bracket foot thickness
foot_w       = 26;     // bracket / clamp foot width
bolt_a       = 8;      // foot bolt, inner
bolt_b       = 24;     // foot bolt, outer
csk_d        = 6.4;    // M3 countersunk head, sits flush in the plate top
jaw_t        = 5;      // jaw plate thickness
jaw_w        = 20;     // inner jaw width (carries the rib)
post_w       = 9;      // outer jaw width. Deliberately narrow: a skewed
                       //   wall sweeps sideways across the jaw, and a wide
                       //   outer plate would block it before it seats.
jaw_h        = 25;     // how far the jaws reach down the bin wall
rib_r        = 3;      // the rounded rib that gives line contact
screw        = 3.4;    // M3 clearance
pinch_screw  = 2.7;    // M3 self-tapping into PLA
grub         = 2.7;    // M3 self-tapping, locks the pipe
lock_boss_d  = 10;     // pad carrying the pipe lock screw
lock_boss_h  = 3;      // how far that pad stands off the block
$fn          = 48;


/* ---------- BRASS HEAT-SET INSERTS ----------
   Set false and every threaded hole goes back to a self-tapping screw
   straight into PLA.

   MEASURE YOUR OWN INSERTS. M3 inserts vary a lot between suppliers:
   4.0 to 4.6mm outside, 3 to 6mm long. insert_d wants to be a couple of
   tenths under the outside diameter so the brass melts its way in.

   Inserts are used in the three places with the plastic to take them:
   the bracket feet, the pipe locks and the thumbscrews. NOT in the plate
   tabs, which are only one wall thick, so those stay self-tapping. */

use_inserts  = true;
insert_d     = 4.2;    // hole for the insert
insert_len   = 4;      // how deep it sits, used to check there is room


/* ------------------------------------------------------------
   Nothing below here needs changing for a different bin.
   ------------------------------------------------------------ */

socket_od = pipe_od + 2 * wall;           // width of the socket block
plate_r   = base_dia / 2 + wall;
foot_x0   = plate_r - socket_len;         // where a foot starts, from centre
bore_d    = pipe_od + pipe_fit;
peak_cut  = bore_d / 2 + 1.5;             // truncated teardrop height
leg_ang   = [60, 180, 300];

function bore_z(base) = base + bore_d / 2 + wall;
function block_h(base) = bore_z(base) + peak_cut + wall;

// Gap must clear the worst case: the thickest wall, skewed as far as a
// rectangular bin can skew it, sweeping sideways across the outer post.
jaw_gap = rib_r + post_w * tan(30) + bin_wall_max / cos(30) + 1;

// How far out each leg has to reach before it meets a wall. On a rectangle
// this differs per leg, which is why the three pipes are cut to different
// lengths. This is what stops the clamps sitting on a circle.
function leg_reach(a) =
    min(abs(cos(a)) < 0.001 ? 1e6 : (bin_x / 2 - bin_t) / abs(cos(a)),
        abs(sin(a)) < 0.001 ? 1e6 : (bin_y / 2 - bin_t) / abs(sin(a)));

jaw_offset = foot_x0 + 9 + jaw_t + rib_r;    // printed hardware at both ends
function pipe_for(a) = leg_reach(a) - jaw_offset;
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

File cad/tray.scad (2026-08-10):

/* ============================================================
   AI SMART BIN  -  sorting tray

   Bolts to the tilt servo. Rubbish lands here, the camera looks
   at it, then the tray tips and drops it into one of three bins.

   THE SHAPE
   A shallow saddle, like a Pringle, same as the Ameru tray.
   NO RIM ANYWHERE. The surface runs straight out to a thin
   edge. A rim would trap the item exactly when you are trying
   to tip it out, which is the opposite of the job.

     ACROSS  (the tilt axis)   sides curl UP 10mm.
       When the head pans, the item gets thrown sideways along
       this axis, and this gentle valley rolls it back to the
       middle. That is the only retention there is, and it is
       enough because it works with gravity rather than
       blocking anything.

     ALONG   (the dump direction)   ends curl DOWN 5mm.
       Where the item leaves. Curling down means there is
       nothing at all to climb, so it goes as soon as it tips.

   HOW STEEP THE ENDS CAN BE
   drop_end is a real trade-off. Curl down too hard and the item
   creeps off on its own while the head is still panning. At 5mm
   the steepest slope is about 9.5 degrees, well under the
   roughly 19 degrees where plastic starts sliding on PLA, so it
   stays put until you actually tip it. Past about 8mm you are
   relying on luck.

   WHAT TO PRINT
     1 x tray     saddle side UP, with a brim.
                  A saddle has no flat face, so this one part
                  does need light support under the two ends and
                  the outer underside. Roughly 8g, and it snaps
                  off a convex surface easily. The top face, the
                  one the camera sees and the item slides on,
                  prints upward and comes out clean.
     1 x spacer   sets the gap between tray and servo bracket.
                  OPTIONAL. Four M3 nylon standoffs of the same height do
                  exactly this job and are already threaded, so you skip the
                  print and the four inserts. See spacer_h below.

   PRINT IT IN A PLAIN LIGHT COLOUR. The camera classifies the
   item against this background, so a busy or shiny surface
   costs you accuracy. Matte white or grey. Not the silk blue.
   ============================================================ */

PART = "tray";      // "tray" | "spacer" | "preview"


/* ---------- MEASURE THESE ----------
   The bolt pattern on your tilt plate. Take the servo horn or the
   MakerWorld bracket's top plate and measure hole to hole.       */

bolt_dx    = 32;    // hole spacing across the tray
bolt_dy    = 15;    // hole spacing along the tray
bolt_d     = 3.4;   // M3 clearance
bolt_csk   = 6.4;   // M3 countersunk head, reached 1.8mm up from bolt_d
csk_run    = 6;     // how far the countersink cone is actually run.
                    //   The saddle is curved, so a cone stopping at a fixed
                    //   height leaves a lip on the high side and the head
                    //   will not drop in. Running it long costs nothing and
                    //   does not move where the head seats.
spacer_h   = 15;    // gap between tray underside and the tilt plate.
                    //   Enough that the tray clears the bracket arms
                    //   at full tilt. Measure, then reprint if wrong.
                    //
                    //   Was 12. It went up because the two screws now come in
                    //   from opposite ends, and at 12 their tips met in the
                    //   middle and neither could pull tight. Taller is the
                    //   safe direction: it only ever adds clearance.


/* ---------- BRASS HEAT-SET INSERTS ----------
   One in each end of the spacer, so the tray screws down into the top and the
   servo bracket screws up into the bottom. Two short screws instead of one
   long one through the lot, and no nut to hold underneath where you cannot
   see it. Set false and it goes back to clearance holes and nuts.

   None of this applies if you use four M3 nylon standoffs instead of printing
   the spacer. A standoff is already a threaded pillar, so it is the same joint
   with none of the work. Same screws either way: M3 x 12 countersunk down from
   the tray, M3 x 8 up from under the servo bracket. The one rule is the same
   too, and it is the reason spacer_h went up: the two screws must not meet in
   the middle. */

use_inserts = true;
insert_d   = 4.2;   // hole for the insert. MEASURE YOURS, they vary
insert_len = 4;     // how deep it sits


/* ---------- SHAPE ---------- */

tray_l     = 120;   // X, the dump direction (ends curl down)
tray_w     = 90;    // Y, along the tilt axis (sides curl up)
rise_side  = 10;    // how far the two long sides curl UP.
                    //   MORE = rolls back to the middle harder
drop_end   = 5;     // how far the two ends curl DOWN.
                    //   MORE = dumps easier, but see the note above
shell_t    = 3;     // wall thickness. It is a shell, not a slab.
end_w      = 12;    // blunt width at the two ends, so they are not points
boss_h     = 3;     // extra material under the middle for the bolts

slices     = 72;    // smoothness along the length
steps      = 28;    // smoothness across the width


/* ------------------------------------------------------------
   The surface: z = rise*(y/half_w)^2 - drop*(x/half_l)^2, a
   hyperbolic paraboloid. Built as a stack of thin cross-sections,
   because the shape is separable: the profile across is the same
   everywhere and simply gets lowered as you move toward an end.
   ------------------------------------------------------------ */

function sag(x)  = drop_end  * pow(x / (tray_l / 2), 2);
function rise(y) = rise_side * pow(y / (tray_w / 2), 2);

// half width at position x, so the outline is a rounded oval
function hw(x) = max(end_w / 2,
                     (tray_w / 2) * sqrt(max(0, 1 - pow(x / (tray_l / 2), 2))));


// Built as one polyhedron over a grid. Not stacked slabs (the oval edge
// comes out visibly stair-stepped) and not hulled slices (hull() takes the
// CONVEX hull, which fills the valley in and turns the shell into a wedge).
nx = 140;   // grid points along the length
ny = 44;    // grid points across the width

function gx(i) = -tray_l / 2 + tray_l * i / (nx - 1);
function gy(i, j) = let (h = hw(gx(i))) -h + 2 * h * j / (ny - 1);
function gz(i, j) = rise(gy(i, j)) - sag(gx(i));

function T(i, j) = i * ny + j;
function B(i, j) = nx * ny + i * ny + j;

// floor_z = undef gives the 3mm shell, which is the tray itself. Give it a
// number instead and you get a solid block under the same top surface, which
// is what caps the boss.
module grid_solid(floor_z = undef) {
    polyhedron(
        points = concat(
            [for (i = [0:nx-1], j = [0:ny-1]) [gx(i), gy(i,j), gz(i,j)]],
            [for (i = [0:nx-1], j = [0:ny-1])
                [gx(i), gy(i,j), floor_z == undef ? gz(i,j) - shell_t : floor_z]]
        ),
        faces = concat(
            // the surface the rubbish sits on
            [for (i = [0:nx-2], j = [0:ny-2])
                [T(i,j), T(i,j+1), T(i+1,j+1), T(i+1,j)]],
            // underside
            [for (i = [0:nx-2], j = [0:ny-2])
                [B(i,j), B(i+1,j), B(i+1,j+1), B(i,j+1)]],
            // the thin edge, all the way round
            [for (i = [0:nx-2]) [T(i,0), T(i+1,0), B(i+1,0), B(i,0)]],
            [for (i = [0:nx-2]) [T(i,ny-1), B(i,ny-1), B(i+1,ny-1), T(i+1,ny-1)]],
            [for (j = [0:ny-2]) [T(0,j), B(0,j), B(0,j+1), T(0,j+1)]],
            [for (j = [0:ny-2]) [T(nx-1,j), T(nx-1,j+1), B(nx-1,j+1), B(nx-1,j)]]
        ),
        convexity = 10
    );
}

module saddle() { grid_solid(); }

// Everything below the top surface. Nothing that gets intersected with this
// can break through the face the camera looks at.
module under_surface() { grid_solid(-40); }


// A rounded rectangle, as four corner posts bridged by two slabs.
// This is exactly hull() of the same four posts: at $fn = 32 each post has a
// vertex square on every axis, so the slab edges meet the posts on their flats
// with nothing sticking out. Written the long way because hull() does not
// convert to STEP, and both the boss and the spacer want this shape.
module rrect(dx, dy, d, h) {
    r = d / 2;
    union() {
        for (x = [-dx / 2, dx / 2], y = [-dy / 2, dy / 2])
            translate([x, y, 0])
                cylinder(d = d, h = h, $fn = 32);
        translate([-dx / 2, -dy / 2 - r, 0]) cube([dx, dy + 2 * r, h]);
        translate([-dx / 2 - r, -dy / 2, 0]) cube([dx + 2 * r, dy, h]);
    }
}
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

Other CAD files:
cad/stl/box_hanger.stl
cad/stl/bracket.stl
cad/stl/camera_clamp.stl
cad/stl/camera_head.stl
cad/stl/clamp.stl
cad/stl/electronics_box.stl
cad/stl/pan_ring.stl
cad/stl/plate.stl
cad/stl/tilt_cradle.stl
cad/stl/tilt_yoke.stl
cad/stl/tray.stl
cad/stl/tray_mount.stl

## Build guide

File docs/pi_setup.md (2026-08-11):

# Pi Prototype — Setup Notes

## Architecture Overview

We pivoted from the original ESP32-CAM + ESP32-C3 dual-board design to a **standalone Raspberry Pi 3B** running everything:

- **USB webcam** for image capture
- **OpenRouter API** for AI waste classification
- **GPIO servos** (pan/tilt) via pigpio hardware PWM
- **Flask web dashboard** for manual control and monitoring

**Not being fitted:** the WS2812B LED ring and the HC-SR04 ultrasonic sensor.
Both were in the design and both were dropped; the reasoning is in
[build_log.md](build_log.md). The LED wiring and states are still written up
below because the code and the dashboard controls are still there, so it is a
solder job and nothing else if it ever goes on.

## Hardware

### Components
| Part | Spec | Notes |
|---|---|---|
| Raspberry Pi 3B | 1GB RAM, 4× USB | Main controller |
| USB Webcam | Generic 640×480 | `/dev/video0` via `v4l2-ctl` mmap streaming, not OpenCV |
| Pan Servo | MG996R | GPIO 17 (Pin 11), signal only |
| Tilt Servo | MG996R | GPIO 27 (Pin 13), signal only |
| LED Ring | WS2812B 16-LED | GPIO 18 (Pin 12), signal only. **Not being fitted** |
| Capacitor | 1000µF electrolytic | Across 5V/GND rail near servos |
| Power | USB-C PD trigger board | Set to **5V ONLY** |

### Wiring
```
PD Board 5V+  ──►  Breadboard RED rail  (+)
PD Board GND  ──►  Breadboard BLUE rail (-)

Pi Pin 2  (5V)   ◄── Breadboard RED rail
Pi Pin 6  (GND)  ◄── Breadboard BLUE rail

Servo 1 (Pan):
  Red    ──► Breadboard RED
  Brown  ──► Breadboard BLUE
  Signal ──► Pi Pin 11 (GPIO 17)

Servo 2 (Tilt):
  Red    ──► Breadboard RED
  Brown  ──► Breadboard BLUE
  Signal ──► Pi Pin 13 (GPIO 27)

LED Ring (not being fitted, kept for reference):
  5V     ──► Breadboard RED
  GND    ──► Breadboard BLUE
  DIN    ──► Pi Pin 12 (GPIO 18)

Capacitor:
  + leg  ──► Breadboard RED
  - leg  ──► Breadboard BLUE (stripe side)
```

### Power Rules
- **PD board must be set to 5V.** Other voltages will destroy the Pi.
- **Do NOT power servos or LEDs from Pi GPIO pins.** Use the external 5V rail.
- **Common ground is automatic** because everything shares the breadboard GND rail.
- **1000µF capacitor** prevents brownouts when servos start moving.

## Pi Configuration

### OS
- Raspberry Pi OS Lite (64-bit)
- Hostname: `smartbin`
- Username: `pi`
- Password: set during Raspberry Pi Imager flashing (not stored in this repo)
- WiFi: your own SSID / passphrase (configured in Imager or `raspi-config`)
- Static IP: a fixed address on your LAN

> Secrets (SSH password, Wi-Fi passphrase) are intentionally kept out of the repo.
> For deployment, provide them via environment variables — see below.

### Installed Packages
```bash
sudo apt install -y python3-pip python3-venv v4l-utils libopenjp2-7
pip install flask httpx pigpio paramiko --break-system-packages
```

**OpenCV:** No longer required — camera capture uses `v4l2-ctl` directly.
(If you ever need cv2 on the Pi 3B, use pip's `opencv-python-headless`, never the apt version — see `docs/pi_cv2_hang.md`.)

### pigpio Daemon
The daemon must be running for jitter-free servo control:
```bash
sudo pigpiod
```
To verify: `ps aux | grep pigpiod`

## How I SSH to the Pi

### Why Paramiko?
I am an AI assistant running in a tool environment. Standard interactive `ssh` commands hang waiting for password input because there is no TTY for me to type into. `sshpass` is not installed. `plink` timed out.

**Paramiko** (Python SSH library) works because it handles authentication programmatically. Credentials come from the environment (`PI_HOST` / `PI_USER` / `PI_PASS`), never hardcoded:
```python
import os, paramiko
client = paramiko.SSHClient()
client.set_missing_host_key_policy(paramiko.AutoAddPolicy())
client.connect(
    os.environ["PI_HOST"],
    username=os.environ.get("PI_USER", "pi"),
    password=os.environ["PI_PASS"],
)
stdin, stdout, stderr = client.exec_command('whoami')
print(stdout.read().decode())
```

For **sudo** commands, open a PTY and send the password:
```python
transport = client.get_transport()
chan = transport.open_session()
chan.get_pty()
chan.exec_command('sudo apt update')
chan.send(os.environ["PI_PASS"] + '\n')
```

## Software Stack

### File Structure on Pi
```
/home/pi/smartbin/
└── src/
    ├── pi/
    │   ├── __init__.py
    │   └── hardware.py       # Servos (pigpio + slew smoothing), v4l2 camera, LED
    └── web/
        ├── app.py            # Flask API + dashboard routes
        ├── animations.py     # Server-side keyframe animation engine
        ├── config.py         # --mock / --pi mode flags
        ├── database.py       # SQLite: history, calibration, sequences, providers
        ├── llm.py            # VLM provider abstraction
        ├── templates/pi/     # Dashboard templates + partials
        └── static/           # app.css + js/pi/ modules
```

### File Structure Locally
The repo layout is in the [root README](../README.md#project-structure). It is
not repeated here, because the copy that used to be here went stale.

### Key Endpoints
| Endpoint | Method | Description |
|---|---|---|
| `/` | GET | Dashboard |
| `/api/health` | GET | CPU temp, uptime, WiFi, pigpio status |
| `/api/camera/stream` | GET | MJPEG live stream (v4l2 mmap) |
| `/api/servos` | GET | Current position + targets |
| `/api/servos/move` | POST | `{"pan": -1..1, "tilt": -1..1}` (either optional) |
| `/api/home` | POST | Center both servos |
| `/api/led` | POST | `{"color": "red|yellow|green|blue|purple|white|off"}` |
| `/api/sort` | POST | Full sort: capture -> classify -> pan -> dump -> home |
| `/api/classify` | POST | Classify base64 image or device capture |
| `/api/compare` | POST | Same frame through two providers in parallel |
| `/api/animations` | GET | Built-ins + saved sequences + playback state |
| `/api/animations/play` | POST | `{"name"}` or `{"id"}` or `{"keyframes": [...]}` |
| `/api/animations/stop` | POST | Stop playback |
| `/api/animations/custom` | POST/DELETE | Save / delete custom sequences |
| `/api/calibration` | GET/PUT | Bin positions + sequence timing |
| `/api/calibration/test/<cat>` | POST | Run the full sort sequence for a bin |
| `/api/events` | GET | SSE stream for real-time updates |
| `/api/stats`, `/api/stats/hourly`, `/api/history` | GET | Sort statistics |
| `/api/providers` | GET/PATCH | LLM provider settings |

### Starting the Server
```bash
cd /home/pi/smartbin/src/web
python3 -u app.py --pi
```
Runs on `http://<pi-ip>:8080`

## Servo Control

### Why pigpio?
- **gpiozero software PWM** = CPU-timed pulses → jittery servos, coil whine
- **pigpio hardware PWM** = DMA-timed pulses → rock solid, zero jitter

### pigpio vs gpiozero Pulsewidths
| Position | gpiozero `value` | pigpio pulsewidth (µs) |
|---|---|---|
| Full left | -1.0 | 500 |
| Center | 0.0 | 1500 |
| Full right | 1.0 | 2500 |

### Category Presets (Bin Layout)
Bin is divided into 3 thirds (top-down view):
```
┌───────────┬───────────┬───────────┐
│           │           │           │
│  GENERAL  │ RECYCLING │  COMPOST  │
│  pan -0.7 │  pan  0.0 │  pan +0.7 │
│     🗑️    │    ♻️     │    🌱     │
└───────────┴───────────┴───────────┘
              ▲ mechanism
```

### Sort Sequence
1. ↔️ Pan to bin third
2. ↕️ Tilt to dump (tilt_dump = -0.6)
3. ↕️ Tilt back to rest (tilt_rest = 0.0)
4. ↔️ Pan back to center

### Tuning
Edit `CATEGORY_PRESETS` in `src/pi/hardware.py` to adjust:
- `pan`: position over each bin third
- `tilt_dump`: how far to tip for item to slide off
- `tilt_rest`: horizontal position
- Timing: `SORT_PAN_SETTLE_S`, `SORT_DUMP_HOLD_S`, `SORT_RETURN_S`

## LED States

The ring is **not being fitted**, so none of this happens in hardware. The
`/api/led` endpoint and the dashboard swatches still work and still drive these
colors, so the table is what would light up if the ring were ever soldered on.

| State | Color |
|---|---|
| Idle | White (dim) |
| Capturing/Classifying | Blue |
| Sorting (panning) | Yellow |
| General waste | Red |
| Recycling | Yellow |
| Compost | Green |
| Error | Purple |

## Troubleshooting

### Pi won't boot (blinking red LED)
- PD board is not set to 5V. Check dip switches.

### Camera not detected
- `ls /dev/video*` should show `/dev/video0` plus internal Pi devices
- If only internal devices (video10+), webcam is not plugged in or not powered

### cv2 import hangs (FIXED)
- The apt `python3-opencv` (4.10.0) deadlocks on import — do NOT use it
- Fix: `pip install opencv-python-headless` (4.13.0 works fine)
- See `docs/pi_cv2_hang.md` for details

### Camera stream dark/flashing
- Camera needs time for auto-exposure to adjust
- v4l2 mmap mode keeps camera open continuously (fixed)
- First 5 frames are skipped (warmup)

### Servos jitter
- pigpiod is not running. Start it: `sudo pigpiod`
- gpiozero fallback is active. Check `hardware.py` uses pigpio.

### Flask won't start
- Check log: `cat /tmp/flask.log`
- Port 8080 in use: `pkill -9 -f "python3.*app.py"` then restart

### "GPIO busy" error
- Another process is holding the GPIO pin. Kill old servo scripts: `pkill -f hold_`

### Gamepad not working
- Press a button to wake it up (auto-detected via Gamepad API)
- Check browser console for `[GP]` logs
- Only works over HTTPS or localhost (browser security)

## Deployment
Use `tools/deploy.py` to push code to the Pi:
```bash
python tools/deploy.py              # Upload + restart
python tools/deploy.py --status     # Check if running
python tools/deploy.py --logs       # View Flask logs
```

## Git Branch
All Pi prototype work lives on the **`pi-prototype`** branch (branched from `master`).

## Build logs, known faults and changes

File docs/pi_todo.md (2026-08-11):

# Pi Prototype — TODO

## Hardware
- [x] Raspberry Pi 3B booted and networked (static LAN IP)
- [x] USB webcam detected and capturing (`/dev/video0`)
- [x] Pan servo wired to GPIO 17 (Pin 11)
- [x] Tilt servo wired to GPIO 27 (Pin 13)
- [x] 1000µF capacitor on 5V rail
- [x] Common ground via breadboard power rail
- [x] External 5V from USB-C PD board (set to 5V!)
- [x] Pan-tilt bracket physically assembled
- [x] Servo jitter fixed (pigpio hardware-timed PWM)
- [ ] Mount USB webcam on pan-tilt bracket
- [ ] Add physical power switch or shutdown button
- [ ] Print the fourteen pieces. Orientation, supports and settings are in
      [`cad/README.md`](../cad/README.md); start with one bracket

### Dropped
- ~~Wire WS2812B LED ring to GPIO 18~~ and ~~test its colors~~. Not being
  fitted. The code and the dashboard controls stay, so it is a solder job if it
  ever goes on. See [build_log.md](build_log.md)
- ~~HC-SR04 ultrasonic item detection~~. Never wired, and now dropped
- ~~Enclose in temporary housing for demo~~. Superseded by the printed
  electronics box

## Software
- [x] Real hardware abstraction (`src/pi/hardware.py`)
- [x] Servo slew-rate smoothing (50Hz motion thread — smooth manual control)
- [x] Single dashboard at `/` (clean dark UI, XY pad, throttled input)
- [x] Server-side animation engine + custom sequence editor
- [x] Bin calibration stored in DB, editable + testable from the dashboard
- [x] "Snap & Sort" pipeline: capture -> VLM classify -> calibrated sort -> LED
- [x] Model comparison (two providers on the same frame)
- [x] Stats view: totals, breakdown, confidence/latency, 24h chart
- [x] Gamepad + keyboard control routed through throttled sender
- [x] v4l2 mmap camera streaming (continuous, stable exposure)
- [x] Directory-sync deploy script (`tools/deploy.py`)
- [ ] **Test servo slew smoothing on real hardware (Pi currently unplugged)**
- [ ] Auto-start Flask on boot (`python tools/deploy.py --setup`)
- [ ] Calibrate servo positions for actual bin thirds (use Calibration tab)
- [ ] Add confidence threshold filter (ignore < 0.7)
- [ ] Error handling for camera disconnection

## AI / VLM
- [x] OpenRouter provider configured
- [x] Vision prompt optimized for Australian waste rules
- [x] Classify endpoint working with base64 webcam capture
- [ ] Test with real waste items under final lighting
- [ ] Compare model accuracy (use the dashboard's Compare modal)
- [ ] Fine-tune prompt for specific bin geometry

## Deployment
- [x] `tools/deploy.py` directory sync (src/pi + src/web, skips venv/db/pycache)
- [x] systemd service files (`src/systemd/`, installed via `--setup`)
- [x] Documentation updated for the redesigned dashboard
- [ ] Backup SD card image before demo day

## Known Issues
- [ ] cv2 import deadlocks on Pi 3B if the apt version is installed — cv2 is no
      longer a dependency, but see `docs/pi_cv2_hang.md` if it comes back
- [ ] Servo range may need mechanical calibration after webcam is mounted

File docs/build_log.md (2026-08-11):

# Build log

A dated record of what has actually been built, so the portfolio can be written
from fact rather than memory. [pi_todo.md](pi_todo.md) is
the list of what is left; this is the list of what happened.

**Add a new entry at the top when something gets built, printed, wired or
tested.** Photograph it at the time. A photo taken later, with the thing already
working, is not evidence of the step.

---

## Where it stands: 11 August 2026

### Built and working

The electronics and software half of the prototype runs.

| | |
| :--- | :--- |
| Pan-tilt head | Bought MakerWorld bracket, 2 x MG996R servos, assembled |
| Controller | Raspberry Pi 3B, on the LAN, code deployed and running |
| Power | USB-C PD trigger board on a separate 5V rail, 1000uF capacitor, common ground through the breadboard |
| Camera | USB webcam capturing through `/dev/video0`, **not yet mounted** on the head |
| Motion | Servo jitter solved with pigpio hardware-timed PWM |
| Software | Dashboard, classify-and-sort pipeline, animation engine, calibration, stats. See the root README |

### Designed but not made

**None of the eleven printed parts exist yet.** Hub plate, three leg brackets,
two bin clamps, one camera clamp, camera head, pan ring, tilt yoke, tilt cradle,
sorting tray, box hanger and electronics box are modelled in Fusion, verified
against calculated geometry, and not printed. That is eleven designs and
fourteen pieces off the printer.

The bought MakerWorld pan-tilt **has** been built, and is now superseded by the
pan ring, tilt yoke and tilt cradle. Its servos move across; the printed part of
it does not get used.

Also not yet bought or made: the 60L bin, the three lengths of 20mm PVC
conduit, the M3 brass inserts, and the bags and bulldog clips.

How to print them, which way up each one goes and what to print first is in
[../cad/README.md](../cad/README.md).

So at this date the mechanism has been **designed and checked, not built or
tested**. Anything written up about it should say so.

### What the checking did and did not prove

Fourteen faults were found and fixed before printing, listed in
[mechanical_iteration_log.md](mechanical_iteration_log.md). That work is real
and worth claiming, but be precise about it: every part was verified against
independently calculated geometry, which proves the model matches its intent.

It cannot prove the parts fit each other in the hand, or that the tripod is
stiff enough, or that items land where the maths says. Those need the printer.

---

## Entries

### 12 August 2026: how to print the fourteen pieces, worked out from the meshes

Everything was modelled, checked and exported, and **nothing said which way up
any of it goes on the bed**. Printing was the next job and the information
needed to start it did not exist.

Printer is a Bambu Lab P1S. Every part fits the 256mm bed; the longest is the
electronics box at 190mm.

**Measured, not eyeballed.** Each part was tried in all six ways it can sit,
and for each the downward-facing area was measured off the exported mesh. Faces
more than 45 degrees off vertical were counted as overhang, anything already
lying on the bed was excluded, and the remainder was split into patches sharing
an edge. That last step is what made the answer useful: grouping by height
alone made the electronics box look like it had a 190mm span to bridge, when
what it actually has is a row of separate windows, each a few mm across.

The result is better than expected. **Eight of the eleven designs need no
support at all**, which is the 45 degree flanks from the shelling job paying
off. Three need it, and each in one identifiable place:

| Part | Where | Area |
| :--- | :--- | ---: |
| camera clamp | roof closing the camera post socket, 20 x 21mm | 363 mm2 |
| tilt yoke | roof of the 25.5mm servo horn pocket | 427 mm2 |
| tray | nearly the whole underside | 8.6 cm2 |

**The tray is the one to watch.** It is a saddle, and measuring it showed it has
no flat face anywhere: laid down it touches the bed on two end edges and
nothing in between, 0 mm2 of contact. Standing it on end cuts the support from
8.6 to 0.3 cm2, and that is still the wrong answer, because it puts the layers
on edge in a part that gets loaded sideways and stands it 120mm tall on 36 mm2
of bed. It gets printed flat with supports and a brim.

All fourteen pieces come to **354.5 cm3 solid, 440g of PLA**. Sliced with walls
and infill it should land somewhere near 200 to 265g, but that part is an
estimate and only the slicer knows.

Written up in [../cad/README.md](../cad/README.md), along with the settings and
the argument for printing **one bracket first**: it is the smallest structural
part at 14.7 cm3 and the only one that tests an insert hole, a conduit socket
and a lock screw at the same time. Those are three of the numbers the same
document already flags as unverified, so one 15 cm3 print settles them before
the other thirteen pieces are committed.

**Not done:** still nothing printed. This is a plan for printing, not evidence
of it, and the support calls are calculated from geometry rather than observed
on a bed.

### 12 August 2026: the LED ring and the ultrasonic sensor are dropped

Neither is going on the build.

The **HC-SR04 ultrasonic sensor** was going to detect an item landing on the
tray and trigger the camera by itself. It was never wired on the Pi prototype;
it belonged to the ESP32 design, where a microcontroller had the spare timing
to watch it. On the Pi the dashboard's Snap and Sort button does the same job,
and a sensor that only saves a button press is not worth the wiring, the 5V to
3.3V divider on the Echo pin, or a hole in a part that is already designed.

The **WS2812B LED ring** was going to show status by colour. It is dropped for
the same kind of reason: nothing in the design ever held it, the dashboard
already reports every stage of a sort live over SSE, and it was the one
remaining electronic part with no home in the CAD.

**The code stays.** `/api/led`, the colour swatches on the dashboard and
`LEDController` in `hardware.py` are all still there and still work, and the
controller is a no-op until an actual ring is present. If one goes on later it
is a solder job and nothing else. That is why this is recorded here as a build
decision rather than as a deletion.

Both are still in the PowerPoint, and they should stay there. Considering a
component and then dropping it with a reason is design process, and the deck is
where that gets marked. The sensor comparison table that picked the HC-SR04
over an IR sensor and a laser rangefinder is still honest work; it just ends
differently now.

Docs updated: [pi_setup.md](pi_setup.md), [pi_todo.md](pi_todo.md) and the root
README.

### 11 August 2026: the two parts the crash rolled back are rebuilt

**This clears the blocker below.** All three jobs were checked against the
committed exports rather than by eye, because those exports are the only record
of what the parts are supposed to be.

**The hub plate is rebuilt natively in Fusion.** Importing the committed
`cad/step/plate.step` and reading its faces gave the design back exactly: a 132
disc 4mm thick, three 26mm spokes, three kidney cutouts between them, a
41.6 x 21mm slot for the pan servo offset 10.2mm so the servo's shaft lands on
centre, and nine holes on the spoke axes. It was then drawn from those numbers
as seven features, not imported as a dumb solid, because the feature tree is
what the course marks.

It measures **28295.24 mm3 against the committed 28295.2**, with the same 45
faces and the same two face areas to 0.01 mm2.

**The tilt yoke's lost edit was found and put back.** Comparing it to
`cad/step/tilt_yoke.step` face by face located the missing 149.50 mm3 as a
20 x 3.25 x 2.30mm notch, which is fault 12's relief for the tilt servo's
flange. Cutting it brings the yoke to **39312.94 mm3 against the committed
39312.94**, with 51 faces both. Re-exporting now produces an STL byte-identical
to the one already in git, which is as strong as this evidence gets.

**The camera post has a lock screw at last.** The socket wall is 2.97mm, too
thin for a brass insert, so a pad stands 4mm proud of it on the outboard side
and carries an M3 x 10 into the conduit, 26mm above the rim. Written up in
[../cad/README.md](../cad/README.md).

**Interference over all sixteen parts is down from seven overlaps to five**, and
none of the five is a printed part against another printed part. See
[mechanical_design.md](mechanical_design.md).

**And the cause of the original loss turned up on the way:** Fusion reported a
save it had not performed. That is almost certainly how the plate rebuild was
lost, and it is written up under Toolchain notes in
[mechanical_iteration_log.md](mechanical_iteration_log.md).

### 11 August 2026: the electronics had nowhere to live either

The same gap as the camera, found the same way. The Pi, the breadboard, the PD
trigger board, the capacitor and the wiring were loose on a desk, and nothing in
the design held any of them.

Sonny asked for a detachable box and suggested underneath. Underneath does not
work, and the reasons are worth keeping: the leg brackets hang to 27.4mm below
the rim so a box has to start below them, which is where the three bags
converge, and the Pi would come out through the rubbish. It would also have to
bolt to the hub plate, which is the part this session cannot touch.

**Done.** Two parts, both outside the bin, neither of which changes any existing
part:

- A *box hanger*, 18113.7 mm3, that hooks over the rim. The weight goes into the
  rim through a flat-roofed slot rather than into a friction pinch, because one
  hanger holding about 300g on a 33mm arm is not the same problem as three
  clamps sharing a tripod. The jaw is the bin clamp's rib and thumbscrew, so it
  still grips a rectangular bin, a round bin or a box.
- An *electronics box*, 61960.3 mm3, 185 x 62 x 40mm inside, hanging on the
  hanger's 45 degree cleat. It lifts straight off with one hand.

Why it is two parts, and why the walls are cut to a frame, are in
[mechanical_design.md](mechanical_design.md). The fault found while fitting it
is 15 in [mechanical_iteration_log.md](mechanical_iteration_log.md).

**Checked, not assumed.** Both meshes are closed manifolds with no open edges.
Both agree with volumes calculated by hand from the design dimensions: the
hanger to 0.003% and the box to 0.03%, the difference being faceting on the
rounded corners. The cleat and its notch were probed face by face to confirm the
45 degree bearing surfaces meet and that the back wall is still closed behind
the notch.

Both parts are **in the assembly**, on the long side wall, and Fusion's own
interference analysis has been run on all sixteen. Neither new part touches
anything: not the bin wall it hooks over, not the clamp 14.8mm away, not each
other. Probed point by point, the hanger's roof sits over the rim, its slot
straddles the 4.5mm wall, and the box hangs with a 10mm gap to the bin.

That same run turned up **seven overlaps that were already there**. The biggest
was the pan servo inside the rolled-back hub plate, which is the entry below
rather than anything new. The others were conduits seated about 1mm too deep in
their clamps and clamp ribs pressed into the bin walls. Two of the seven went
when the plate and yoke were rebuilt later the same day; the five that remain
are in [mechanical_design.md](mechanical_design.md).

**Not done, and it matters:**

- Nothing is printed, so none of it is confirmed in the hand.
- The seven overlaps above are not fixed. Fixing the first one means settling
  the hub plate, which is Sonny's call.
- The breadboard was measured off the prototype photograph, not with calipers.
  If it turns out to be a full-size 165mm board rather than a half-size 83mm
  one, the box has to be redrawn.

### 11 August 2026: Fusion crashed and took the hub plate rebuild with it

**Fixed later the same day**, see the entry at the top. Both parts are back and
the export script is safe to run again. The rest of this entry is the record of
what went wrong.

Fusion crashed mid-session. On restart, two parts had gone backwards to a state
older than what is committed in this repo:

| Part | In Fusion now | Committed in git | |
| :--- | ---: | ---: | :--- |
| Hub plate | 32,150 mm3, 11mm thick, retaining tabs present | 28,289 mm3, 4mm thick, no tabs | the pre-rebuild plate |
| Tilt yoke | 39,462 mm3 | 39,311 mm3 | some later edit lost |

Both documents report themselves as their own latest version, so the rebuild had
never been saved to the cloud. It had been living as an unsaved edit in Fusion's
memory, surviving between sessions, and the crash took it.

**The geometry itself is not lost.** `cad/stl/plate.stl` and `cad/step/plate.step`
in git are the correct 4mm plate, and the same for the yoke. What is lost is the
Fusion feature history for those two parts, which is the thing the course wants
to see.

The choice at the time was to rebuild the plate's features in Fusion or to
import the committed STEP as a solid. **Rebuilt**, because an imported solid
carries no feature history and the history is what the course marks. Until that
was done the full export script had to be left alone, since it would have
overwritten the good committed plate and yoke with the rolled-back shapes.

Only the three parts changed that day were exported, by a cut-down version of the
export script naming just those parts.

### 11 August 2026: the sockets were blocks with holes in them, so they got shelled

Sonny asked whether the clamps could use less filament. They could: a pipe socket
was a round bore through a solid block, 36% plastic and 64% air, with 1.49mm of
wall at the equator and 6mm sitting uselessly in the corners.

The outer face now follows the bore, offset 2.5mm, with 45 degree flanks so it
still prints unsupported. All six socketed parts drop from **114.3 to 95.0 cm3**,
about 24g of PLA. Reasoning is in [mechanical_design.md](mechanical_design.md),
the numbers and the fault it turned up are iteration 3 and fault 14 in
[mechanical_iteration_log.md](mechanical_iteration_log.md).

The fault is the part worth reading. Cutting all four corners off every part
opened the camera post socket to the air and took away the post's end stop.
Corners are only waste where nothing is attached below them.

**Checked, not assumed:** the pipe lock screw still has 6.2000mm of thread, the
minimum wall is still 1.50mm, and the post bore is closed again across its full
width.

**Not done:** nothing is printed, so none of this is confirmed in the hand. The
real filament saving will be smaller than 16.8%, because these are solid volumes
and some of what went was infill rather than solid plastic.

### 11 August 2026: the camera would have mounted upside down

Found by probing the camera head's solid down the bolt axis instead of looking
at a render. The 1/4-20 bolt recess had been cut into the **top** of the side
arm, so the thread pointed down and the webcam would have hung underneath it
inverted. Both this log and [../cad/README.md](../cad/README.md) already said
the head was recessed underneath with the thread pointing up, so the model and
the write-up had quietly disagreed since the part was made.

**Done.** The recess moved to the underside. The part is otherwise untouched and
still 18806.1 mm3, which is the whole lesson: the volume check that signed this
part off cannot tell which end of a hole a pocket is at. Written up as fault 13
in [mechanical_iteration_log.md](mechanical_iteration_log.md).

**Also corrected:** the camera's sighting numbers. They had been worked out from
the **post's** axis at 142.5mm from the tray centre, but the camera sits on the
arm, which reaches back to 122.5mm. The camera looks down at **52 degrees from
199mm**, not the 46 degrees from 219mm quoted before.

### 11 August 2026: the head was too tall, so it got rebuilt

The tray sat **147mm above the bin rim** and the whole thing towered over the
bin. Measured against the assembly, 85mm of that 147 was the bought MakerWorld
tracker stacking two servos on top of each other:

| From | To | mm |
| :--- | :--- | ---: |
| Bin rim | hub plate underside | 9.0 |
| | hub plate | 11.0 |
| Plate top | top of the tracker's stand | 27.0 |
| | gap over the pan servo | 14.5 |
| U-bracket bottom | tilt axis | 44.3 |
| Tilt axis | tray underside | 40.9 |

The last row is the worst of it. The tracker stands its tilt servo on end
inside a U-bracket, so the servo body finishes **37mm above the tilt axis** and
the tray has to clear the servo before it clears anything else.

We had only the STL when the tracker was bought, so it was treated as fixed.
Having the STEP meant it could be replaced.

**Done.** Three new printed parts, plus a change to the hub plate. How it works
is in [mechanical_design.md](mechanical_design.md); why each choice was made,
and the three faults found while fitting it, are in
[mechanical_iteration_log.md](mechanical_iteration_log.md).

The result: **tray underside 147mm above the rim becomes 82mm**, and the head
uses 100.8cm3 of plastic against the 138.4cm3 it replaces.

**Also changed:** the camera post is now cut to 235mm, not 300. The tray
dropped 65mm underneath it, and the post came down by the same 65mm to hold the
camera's view of the tray exactly where it was: 52 degrees from 199mm away.
Leaving the 300 would have made it 61 degrees from 254mm.

**Not done:** nothing is printed, so none of this is confirmed in the hand. The
one number worth checking with calipers before printing is the tilt servo's
flange hole pattern, listed in [../cad/README.md](../cad/README.md).

### 11 August 2026: the camera had nowhere to go

Found while checking what was left to do. The pan-tilt's own camera plate was
removed so the tray mount could take its place, and nothing was ever designed to
hold the webcam or the LED ring. Printing the five parts and assembling them
would have ended with the camera in mid air.

Sonny's fix: put a vertical length of the same 20mm conduit on top of one of the
bin clamps, with a camera mount on the end of it. Better than mounting off the
hub plate, which is exactly where the tray sweeps when it tilts.

**Done:**

- A *camera clamp*, a copy of the bin clamp with a 20mm socket on top. Verified
  at 30919.1 mm3, the original clamp plus a socket of exactly the calculated
  volume.
- A *camera head* that caps the post. Verified at 18806.1 mm3, 0.000% off the
  calculated figure. The webcam turned out to have a 1/4-20 tripod thread, which
  is far better than clipping to something, so the head carries a 1/4-20 bolt
  through a side arm with the head recessed underneath. The arm points at the
  tray so the pipe is not in shot.
- Both are in the assembly with a 300mm length of conduit between them. That
  puts the camera 52 degrees above the tray, 199mm away.

**Not done at the time:** no lock screw for the post, so nothing stopped the
pipe turning and swinging the camera off aim. Added later the same day, see the
entry at the top.

Print two standard clamps and one camera clamp. The camera clamp cannot print
flat on the same face as the standard one, since the socket grows out of it.

### 11 August 2026: decided against printed bin dividers

Three ordinary bin bags on bulldog clips, one per sector, instead of a divider
part. The three legs already cut the opening into three, so no new part is
needed. Reasoning and the drop-geometry numbers are in
[mechanical_design.md](mechanical_design.md).

Removes a part from the build and about $10 from the budget. Costs some rigidity
once the bags are fairly full.

The bigger reason came out afterwards: cut dividers would have to be re-cut for
every new bin, which would have cancelled out the fits-any-bin property the
clamps and the cut-to-length legs were designed for. Bags keep it, so moving the
whole rig to a different bin is three saw cuts and nothing else.

### 11 August 2026: parts rebuilt natively in Fusion

The hub and tray were originally drawn in OpenSCAD. The course needs the CAD to
be Fusion work, so all five parts were rebuilt there and Fusion became the
design source. The OpenSCAD files stay in the repo because their history is the
only copy of the early versions, and
[cad/renders/](../cad/renders/README.md) draws the design-evolution pictures
from it.

---

## What to capture as you build

The portfolio is marked on the process, so the awkward moments are worth more
than the tidy result.

- **Photograph a part coming off the printer**, before cleanup, especially if
  something went wrong.
- **Photograph anything that did not fit**, and write down the measurement.
  A part that had to be reprinted is stronger evidence than one that did not.
- **Write down numbers when you test**, not impressions. How many items out of
  how many landed in the right sector. What tilt speed. How long a sort took.
- **Note anything that surprised you.** That is where the design reasoning in
  the write-up comes from.

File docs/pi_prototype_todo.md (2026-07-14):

# Pi Prototype — TODO

## Hardware
- [x] Raspberry Pi 3B booted and networked (static LAN IP)
- [x] USB webcam detected and capturing (`/dev/video0`)
- [x] Pan servo wired to GPIO 17 (Pin 11)
- [x] Tilt servo wired to GPIO 27 (Pin 13)
- [x] 1000µF capacitor on 5V rail
- [x] Common ground via breadboard power rail
- [x] External 5V from USB-C PD board (set to 5V!)
- [x] Pan-tilt bracket physically assembled
- [x] Servo jitter fixed (pigpio hardware-timed PWM)
- [ ] Mount USB webcam on pan-tilt bracket
- [ ] Wire WS2812B LED ring to GPIO 18 (Pin 12)
- [ ] Test LED ring colors from software
- [ ] Add physical power switch or shutdown button
- [ ] Enclose in temporary housing for demo

## Software
- [x] Real hardware abstraction (`src/pi/hardware.py`)
- [x] Servo slew-rate smoothing (50Hz motion thread — smooth manual control)
- [x] Single dashboard at `/` (clean dark UI, XY pad, throttled input)
- [x] Server-side animation engine + custom sequence editor
- [x] Bin calibration stored in DB, editable + testable from the dashboard
- [x] "Snap & Sort" pipeline: capture -> VLM classify -> calibrated sort -> LED
- [x] Model comparison (two providers on the same frame)
- [x] Stats view: totals, breakdown, confidence/latency, 24h chart
- [x] Gamepad + keyboard control routed through throttled sender
- [x] v4l2 mmap camera streaming (continuous, stable exposure)
- [x] Directory-sync deploy script (`deploy.py`)
- [ ] **Test servo slew smoothing on real hardware (Pi currently unplugged)**
- [ ] Auto-start Flask on boot (`python deploy.py --setup`)
- [ ] Calibrate servo positions for actual bin thirds (use Calibration tab)
- [ ] Add confidence threshold filter (ignore < 0.7)
- [ ] Error handling for camera disconnection
- [ ] LED animations once ring is wired

## AI / VLM
- [x] OpenRouter provider configured
- [x] Vision prompt optimized for Australian waste rules
- [x] Classify endpoint working with base64 webcam capture
- [ ] Test with real waste items under final lighting
- [ ] Compare model accuracy (use the dashboard's Compare modal)
- [ ] Fine-tune prompt for specific bin geometry

## Deployment
- [x] `deploy.py` directory sync (src/pi + src/web, skips venv/db/pycache)
- [x] systemd service files (`src/systemd/`, installed via `--setup`)
- [x] Documentation updated for the redesigned dashboard
- [ ] Backup SD card image before demo day

## Known Issues
- [ ] cv2 import deadlocks on Pi 3B if the apt version is installed — cv2 is no
      longer a dependency, but see `docs/pi_cv2_hang.md` if it comes back
- [ ] Servo range may need mechanical calibration after webcam is mounted

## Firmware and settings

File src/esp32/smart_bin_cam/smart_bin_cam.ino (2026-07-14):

// ═════════════════════════════════════════════════════════════════════════════
//  AI SMART BIN — ESP32-CAM Firmware
//  Camera + Servo + WS2812B + Web UI + OpenRouter AI Classification
// ═════════════════════════════════════════════════════════════════════════════

#include <ESP32Servo.h>
#include <WiFi.h>
#include <WebServer.h>
#include <Adafruit_NeoPixel.h>
#include <Preferences.h>
#include <ESPmDNS.h>
#include "esp_camera.h"

// ── WiFi ────────────────────────────────────────────────────────────────────
const char* WIFI_SSID     = "YOUR_WIFI_SSID";
const char* WIFI_PASSWORD = "YOUR_WIFI_PASSWORD";

// ── Camera (AI-Thinker ESP32-CAM pinout) ──────────────────────────────────
#define CAM_PWDN    32
#define CAM_RESET   -1
#define CAM_XCLK     0
#define CAM_SIOD    26
#define CAM_SIOC    27
#define CAM_D7      35
#define CAM_D6      34
#define CAM_D5      39
#define CAM_D4      36
#define CAM_D3      21
#define CAM_D2      19
#define CAM_D1      18
#define CAM_D0       5
#define CAM_VSYNC   25
#define CAM_HREF    23
#define CAM_PCLK    22

// ── Peripherals ─────────────────────────────────────────────────────────────
#define SERVO_PIN    13
#define LED_PIN       4
#define LED_COUNT    16

// ── Defaults ────────────────────────────────────────────────────────────────
#define DEFAULT_ANGLE_GENERAL   45
#define DEFAULT_ANGLE_RECYCLING 90
#define DEFAULT_ANGLE_COMPOST  135

// ═════════════════════════════════════════════════════════════════════════════
//  OBJECTS
// ═════════════════════════════════════════════════════════════════════════════
Servo myServo;
Adafruit_NeoPixel ring(LED_COUNT, LED_PIN, NEO_GRB + NEO_KHZ800);
WebServer server(80);
Preferences prefs;

// ═════════════════════════════════════════════════════════════════════════════
//  STATE
// ═════════════════════════════════════════════════════════════════════════════
struct {
  // Servo
  int  targetAngle    = 90;
  int  currentAngle   = 90;
  int  servoSpeed     = 8;
  bool sweeping       = false;
  int  sweepAngle     = 0;
  int  sweepDir       = 1;
  int  sweepInterval  = 15;
  unsigned long lastSweepTime = 0;

  // Category angles
  int angleGeneral   = DEFAULT_ANGLE_GENERAL;
  int angleRecycling = DEFAULT_ANGLE_RECYCLING;
  int angleCompost   = DEFAULT_ANGLE_COMPOST;

  // LED
  int  r = 0, g = 255, b = 136;
  int  brightness = 80;
  bool on = true;
  int  effect = 0; // 0=solid 1=rainbow 2=chase 3=breathe 4=sparkle 5=fire 6=comet
  int  chasePos = 0;
  int  breatheVal = 0, breatheDir = 1;
  unsigned long lastLedTime = 0;

  // System
  unsigned long startTime = 0;
  bool cameraReady = false;
} st;

// ═════════════════════════════════════════════════════════════════════════════
//  LED FX
// ═════════════════════════════════════════════════════════════════════════════
void runLeds(){
  if(!st.on){ ring.clear(); ring.show(); return; }
  unsigned long now = millis();

  switch(st.effect){
    case 0: // Solid
      for(int i=0;i<LED_COUNT;i++) ring.setPixelColor(i, ring.Color(st.r,st.g,st.b));
      ring.show();
      break;

    case 1: // Rainbow
      if(now-st.lastLedTime > 20){
        static uint16_t hue=0;
        for(int i=0;i<LED_COUNT;i++) ring.setPixelColor(i, ring.ColorHSV((hue+i*(65536/LED_COUNT))&0xFFFF));
        ring.show(); hue+=256; st.lastLedTime=now;
      }
      break;

    case 2: // Chase
      if(now-st.lastLedTime > 60){
        ring.clear();
        ring.setPixelColor(st.chasePos, ring.Color(st.r,st.g,st.b));
        ring.setPixelColor((st.chasePos+1)%LED_COUNT, ring.Color(st.r/3,st.g/3,st.b/3));
        ring.show(); st.chasePos=(st.chasePos+1)%LED_COUNT; st.lastLedTime=now;
      }
      break;

    case 3: // Breathe
      if(now-st.lastLedTime > 10){
        st.breatheVal += st.breatheDir*3;
        if(st.breatheVal>=255){ st.breatheVal=255; st.breatheDir=-1; }
        if(st.breatheVal<=0){ st.breatheVal=0; st.breatheDir=1; }
        float s = st.breatheVal/255.0;
        for(int i=0;i<LED_COUNT;i++) ring.setPixelColor(i, ring.Color(st.r*s,st.g*s,st.b*s));
        ring.show(); st.lastLedTime=now;
      }
      break;

    case 4: // Sparkle
      if(now-st.lastLedTime > 50){
        for(int i=0;i<LED_COUNT;i++) ring.setPixelColor(i, ring.Color(st.r,st.g,st.b));
        ring.setPixelColor(random(LED_COUNT), ring.Color(255,255,255));
        ring.show(); st.lastLedTime=now;
      }
      break;

    case 5: // Fire
      if(now-st.lastLedTime > 50){
        for(int i=0;i<LED_COUNT;i++){
          int flicker = random(0, 80);
          int r = constrain(st.r + flicker, 0, 255);
          int g = constrain(st.g + flicker/3, 0, 255);
          int b = 0;
          ring.setPixelColor(i, ring.Color(r,g,b));
        }
        ring.show(); st.lastLedTime=now;
      }
      break;

    case 6: // Comet
      if(now-st.lastLedTime > 40){
        static int pos=0;
        ring.clear();
        for(int i=0;i<5;i++){
          int p=(pos-i+LED_COUNT)%LED_COUNT;
          int br=255-(i*50);
          ring.setPixelColor(p, ring.Color(st.r*br/255,st.g*br/255,st.b*br/255));
        }
        ring.show(); pos=(pos+1)%LED_COUNT; st.lastLedTime=now;
      }
      break;
  }
}

// ═════════════════════════════════════════════════════════════════════════════
//  SMOOTH SERVO & SWEEP
// ═════════════════════════════════════════════════════════════════════════════
void updateServo(){
  // Smooth move toward target
  if(abs(st.targetAngle - st.currentAngle) > 0){
    int step = st.servoSpeed;
    if(abs(st.targetAngle - st.currentAngle) < step) step = 1;
    if(st.targetAngle > st.currentAngle) st.currentAngle += step;
    else st.currentAngle -= step;
    myServo.write(st.currentAngle);
  }

  // Sweep logic
  if(st.sweeping && millis()-st.lastSweepTime > st.sweepInterval){
    st.sweepAngle += st.sweepDir;
    if(st.sweepAngle >= 180){ st.sweepAngle=180; st.sweepDir=-1; }
    if(st.sweepAngle <= 0){ st.sweepAngle=0; st.sweepDir=1; }
    st.targetAngle = st.sweepAngle;
    st.lastSweepTime = millis();
  }
}

// ═════════════════════════════════════════════════════════════════════════════
//  CONFIG SAVE / LOAD
// ═════════════════════════════════════════════════════════════════════════════
void saveConfig(){
  prefs.begin("smartbin", false);
  prefs.putInt("angle", st.targetAngle);
  prefs.putBool("sweep", st.sweeping);
  prefs.putInt("speed", st.servoSpeed);
  prefs.putInt("r", st.r);
  prefs.putInt("g", st.g);
  prefs.putInt("b", st.b);
  prefs.putInt("brt", st.brightness);
  prefs.putInt("fx", st.effect);
  prefs.putBool("on", st.on);
  prefs.putInt("angGen", st.angleGeneral);
  prefs.putInt("angRec", st.angleRecycling);
  prefs.putInt("angComp", st.angleCompost);
  prefs.end();
  Serial.println("Config saved");
}

void loadConfig(){
  prefs.begin("smartbin", true);
  st.targetAngle    = prefs.getInt("angle", 90);
  st.sweeping       = prefs.getBool("sweep", false);
  st.servoSpeed     = prefs.getInt("speed", 8);
  st.r              = prefs.getInt("r", 0);
  st.g              = prefs.getInt("g", 255);
  st.b              = prefs.getInt("b", 136);
  st.brightness     = prefs.getInt("brt", 80);
  st.effect         = prefs.getInt("fx", 0);
  st.on             = prefs.getBool("on", true);
  st.angleGeneral   = prefs.getInt("angGen", DEFAULT_ANGLE_GENERAL);
  st.angleRecycling = prefs.getInt("angRec", DEFAULT_ANGLE_RECYCLING);
  st.angleCompost   = prefs.getInt("angComp", DEFAULT_ANGLE_COMPOST);
  prefs.end();
  st.currentAngle = st.targetAngle;
  Serial.println("Config loaded");
}

// ═════════════════════════════════════════════════════════════════════════════
//  CAMERA
// ═════════════════════════════════════════════════════════════════════════════
bool initCamera(){
  camera_config_t config;
  config.ledc_channel = LEDC_CHANNEL_0;
  config.ledc_timer = LEDC_TIMER_0;
  config.pin_d0 = CAM_D0;
  config.pin_d1 = CAM_D1;
  config.pin_d2 = CAM_D2;
  config.pin_d3 = CAM_D3;
  config.pin_d4 = CAM_D4;
  config.pin_d5 = CAM_D5;
  config.pin_d6 = CAM_D6;
  config.pin_d7 = CAM_D7;
  config.pin_xclk = CAM_XCLK;
  config.pin_pclk = CAM_PCLK;
  config.pin_vsync = CAM_VSYNC;
  config.pin_href = CAM_HREF;
  config.pin_sscb_sda = CAM_SIOD;
  config.pin_sscb_scl = CAM_SIOC;
  config.pin_pwdn = CAM_PWDN;
  config.pin_reset = CAM_RESET;
  config.xclk_freq_hz = 20000000;
  config.pixel_format = PIXFORMAT_JPEG;
  config.frame_size = FRAMESIZE_QVGA;     // 320x240 — small, fast upload
  config.jpeg_quality = 12;                // 0-63, lower=better
  config.fb_count = 1;
  config.grab_mode = CAMERA_GRAB_WHEN_EMPTY;

  if(psramFound()){
    config.fb_count = 2;
    config.fb_location = CAMERA_FB_IN_PSRAM;
    Serial.println("PSRAM found, using for camera buffers");
  } else {
    config.fb_location = CAMERA_FB_IN_DRAM;
    Serial.println("No PSRAM, using DRAM");
  }

  esp_err_t err = esp_camera_init(&config);
  if(err != ESP_OK){
    Serial.printf("Camera init failed: 0x%x\n", err);
    return false;
  }

  // Tweak sensor settings for better indoor photos
  sensor_t * s = esp_camera_sensor_get();
  if(s){
    s->set_brightness(s, 0);
    s->set_contrast(s, 1);
    s->set_saturation(s, 0);
    s->set_whitebal(s, 1);
    s->set_awb_gain(s, 1);
    s->set_wb_mode(s, 0);
    s->set_exposure_ctrl(s, 1);
    s->set_aec2(s, 1);
    s->set_gain_ctrl(s, 1);
    s->set_agc_gain(s, 0);
    s->set_gainceiling(s, (gainceiling_t)6);
    s->set_bpc(s, 0);
    s->set_wpc(s, 1);
    s->set_raw_gma(s, 1);
    s->set_lenc(s, 1);
    s->set_hmirror(s, 0);
    s->set_vflip(s, 0);
    s->set_dcw(s, 1);
  }

  Serial.println("Camera ready");
  return true;
}

// ═════════════════════════════════════════════════════════════════════════════
//  WEB HANDLERS
// ═════════════════════════════════════════════════════════════════════════════

void sendCORS(){
  server.sendHeader("Access-Control-Allow-Origin", "*");
  server.sendHeader("Access-Control-Allow-Methods", "GET, POST, OPTIONS");
  server.sendHeader("Access-Control-Allow-Headers", "Content-Type");
}

void handleRoot();
void handleStream();
void handleCapture();
void handleSet();
void handleSweep();
void handleServoSpeed();
void handleSort();
void handleConfigAngles();
void handleLedPower();
void handleLedBright();
void handleLedColor();
void handleLedEffect();
void handleConfigSave();
void handleReboot();
void handleInfo();

void handleRoot(){
  WiFiClient client = server.client();
  String header = "HTTP/1.1 200 OK\r\nContent-Type: text/html\r\nConnection: close\r\n\r\n";
  client.write(header.c_str());

  const char* p = INDEX_HTML;
  size_t total = strlen(p);
  size_t sent = 0;
  while(sent < total){
    size_t chunk = total - sent;
    if(chunk > 1024) chunk = 1024;
    client.write(p + sent, chunk);
    sent += chunk;
    yield();
  }
}

void handleStream(){
  WiFiClient client = server.client();
  String response = "HTTP/1.1 200 OK\r\n";
  response += "Content-Type: multipart/x-mixed-replace; boundary=frame\r\n";
  response += "Access-Control-Allow-Origin: *\r\n\r\n";
  client.write(response.c_str());

  int frames = 0;
  unsigned long start = millis();
  while(client.connected()){
    camera_fb_t * fb = esp_camera_fb_get();
    if(!fb) break;

    String boundary = "--frame\r\nContent-Type: image/jpeg\r\nContent-Length: ";
    boundary += String(fb->len) + "\r\n\r\n";
    client.write(boundary.c_str());
    client.write(fb->buf, fb->len);
    client.write("\r\n");
    esp_camera_fb_return(fb);

    frames++;
    // Simple FPS throttle: target ~15fps
    delay(60);

    // Safety: close stream after 60s to free server for other requests
    if(millis() - start > 60000) break;
  }
}

void handleCapture(){
  if(!st.cameraReady){
    server.send(503, "text/plain", "Camera not ready");
    return;
  }
  camera_fb_t * fb = esp_camera_fb_get();
  if(!fb){
    server.send(503, "text/plain", "Capture failed");
    return;
  }

  WiFiClient client = server.client();
  String response = "HTTP/1.1 200 OK\r\n";
  response += "Content-Type: image/jpeg\r\n";
  response += "Content-Length: " + String(fb->len) + "\r\n";
  response += "Access-Control-Allow-Origin: *\r\n";
  response += "Cache-Control: no-cache\r\n\r\n";
  client.write(response.c_str());
  client.write(fb->buf, fb->len);
  esp_camera_fb_return(fb);
}

void handleSet(){
  sendCORS();
  if(server.hasArg("angle")){
    st.targetAngle = constrain(server.arg("angle").toInt(),0,180);
    st.sweeping = false;
  }
  server.send(200,"text/plain","OK");
}

void handleSweep(){
  sendCORS();
  if(server.hasArg("state")){
    st.sweeping = server.arg("state")=="1";
    if(st.sweeping) st.sweepAngle = st.currentAngle;
  }
  server.send(200,"text/plain","OK");
}

void handleServoSpeed(){
  sendCORS();
  if(server.hasArg("val")) st.servoSpeed = constrain(server.arg("val").toInt(),1,30);
  server.send(200,"text/plain","OK");
}

void handleSort(){
  sendCORS();
  if(server.hasArg("category")){
    String cat = server.arg("category");
    st.sweeping = false;
    if(cat == "general"){
      st.targetAngle = st.angleGeneral;
      st.r=255; st.g=30; st.b=30; st.effect=0;
    } else if(cat == "recycling"){
      st.targetAngle = st.angleRecycling;
      st.r=255; st.g=180; st.b=0; st.effect=0;
    } else if(cat == "compost"){
      st.targetAngle = st.angleCompost;
      st.r=0; st.g=255; st.b=60; st.effect=0;
    }
  }
  server.send(200,"text/plain","OK");
}

void handleConfigAngles(){
  sendCORS();
  if(server.hasArg("general"))   st.angleGeneral   = constrain(server.arg("general").toInt(),0,180);
  if(server.hasArg("recycling")) st.angleRecycling = constrain(server.arg("recycling").toInt(),0,180);
  if(server.hasArg("compost"))   st.angleCompost   = constrain(server.arg("compost").toInt(),0,180);
  server.send(200,"text/plain","OK");
}

void handleLedPower(){
  sendCORS();
  if(server.hasArg("state")){
    st.on = server.arg("state")=="1";
    if(!st.on){ ring.clear(); ring.show(); }
  }
  server.send(200,"text/plain","OK");
}

void handleLedBright(){
  sendCORS();
  if(server.hasArg("val")){
    st.brightness = constrain(server.arg("val").toInt(),0,255);
    ring.setBrightness(st.brightness);
  }
  server.send(200,"text/plain","OK");
}

void handleLedColor(){
  sendCORS();
  if(server.hasArg("r")) st.r = constrain(server.arg("r").toInt(),0,255);
  if(server.hasArg("g")) st.g = constrain(server.arg("g").toInt(),0,255);
  if(server.hasArg("b")) st.b = constrain(server.arg("b").toInt(),0,255);
  st.effect = 0;
  server.send(200,"text/plain","OK");
}

void handleLedEffect(){
  sendCORS();
  if(server.hasArg("n")) st.effect = constrain(server.arg("n").toInt(),0,6);
  server.send(200,"text/plain","OK");
}

void handleConfigSave(){
  sendCORS();
  saveConfig();
  server.send(200,"text/plain","SAVED");
}

void handleReboot(){
  sendCORS();
  server.send(200,"text/plain","REBOOTING");
  delay(200);
  ESP.restart();
}

void handleInfo(){
  sendCORS();
  unsigned long uptime = (millis()-st.startTime)/1000;
  String json = "{";
  json += "\"angle\":"+String(st.currentAngle)+",";
  json += "\"target\":"+String(st.targetAngle)+",";
  json += "\"uptime\":"+String(uptime)+",";
  json += "\"sweep\":"+String(st.sweeping?"true":"false")+",";
  json += "\"ip\":\""+WiFi.localIP().toString()+"\",";
  json += "\"rssi\":"+String(WiFi.RSSI())+",";
  json += "\"camera\":"+String(st.cameraReady?"true":"false")+",";
  json += "\"clients\":"+String(WiFi.softAPgetStationNum())+",";
  json += "\"freeHeap\":"+String(ESP.getFreeHeap()/1024)+",";
  json += "\"angleGeneral\":"+String(st.angleGeneral)+",";
  json += "\"angleRecycling\":"+String(st.angleRecycling)+",";
  json += "\"angleCompost\":"+String(st.angleCompost)+",";
  json += "\"ledOn\":"+String(st.on?"true":"false")+",";
  json += "\"ledEffect\":"+String(st.effect)+",";
  json += "\"ledBrightness\":"+String(st.brightness)+",";
  json += "\"ledR\":"+String(st.r)+",";
  json += "\"ledG\":"+String(st.g)+",";
  json += "\"ledB\":"+String(st.b);
  json += "}";
  server.send(200,"application/json",json);
}

// ═════════════════════════════════════════════════════════════════════════════
//  HTML UI
// ═════════════════════════════════════════════════════════════════════════════
const char INDEX_HTML[] PROGMEM = R"rawliteral(
<!DOCTYPE html>
<html lang="en">
<head>
<meta charset="UTF-8">
<meta name="viewport" content="width=device-width,initial-scale=1,user-scalable=no">
<title>AI Smart Bin</title>
<style>
:root{
  --bg:#06060a;--surface:#0f0f14;--surface2:#18181f;--border:#272730;--borderlt:#3f3f4e;
  --text:#e4e4e7;--dim:#a1a1aa;--muted:#71717a;--accent:#6366f1;--accent2:#8b5cf6;
  --general:#ef4444;--recycling:#f59e0b;--compost:#22c55e;--warn:#f97316;
}
*{box-sizing:border-box;margin:0;padding:0;-webkit-tap-highlight-color:transparent;font-family:'Segoe UI',system-ui,sans-serif}
body{background:var(--bg);color:var(--text);min-height:100vh;padding:16px;max-width:900px;margin:0 auto}

/* Header */
header{display:flex;align-items:center;justify-content:space-between;gap:12px;margin-bottom:20px;padding-bottom:16px;border-bottom:1px solid var(--border)}
.brand{display:flex;align-items:center;gap:10px}
.brand-icon{width:36px;height:36px;border-radius:10px;background:linear-gradient(135deg,var(--accent),var(--accent2));display:flex;align-items:center;justify-content:center;font-size:18px}
.brand h1{font-size:1.25rem;font-weight:800;letter-spacing:-0.5px}
.badge{font-size:0.65rem;padding:3px 10px;border-radius:99px;background:rgba(99,102,241,0.15);color:var(--accent);border:1px solid rgba(99,102,241,0.3);font-weight:600}
.status{display:flex;align-items:center;gap:6px;font-size:0.75rem;color:var(--muted)}
.dot{width:7px;height:7px;border-radius:50%;background:var(--compost);animation:pulse 1.5s infinite}
@keyframes pulse{0%,100%{opacity:1}50%{opacity:0.3}}

/* Tabs */
.tabs{display:flex;gap:6px;margin-bottom:20px;background:var(--surface);padding:5px;border-radius:12px;border:1px solid var(--border)}
.tab{flex:1;padding:10px 8px;border-radius:8px;border:none;background:transparent;color:var(--dim);font-size:0.8rem;font-weight:600;cursor:pointer;transition:all .2s;text-align:center}
.tab:hover{color:var(--text)}
.tab.active{background:linear-gradient(135deg,var(--accent),var(--accent2));color:#fff;box-shadow:0 4px 16px rgba(99,102,241,0.3)}

/* Sections */
.section{display:none;animation:fade .25s ease}
.section.active{display:block}
@keyframes fade{from{opacity:0;transform:translateY(6px)}to{opacity:1;transform:none}}

/* Cards */
.card{background:var(--surface);border:1px solid var(--border);border-radius:14px;padding:18px;margin-bottom:14px}
.card-title{font-size:0.7rem;font-weight:700;text-transform:uppercase;letter-spacing:2px;color:var(--muted);margin-bottom:14px;display:flex;align-items:center;gap:8px}

/* Camera */
.cam-wrap{position:relative;background:#000;border-radius:12px;overflow:hidden;border:1px solid var(--border);aspect-ratio:4/3}
.cam-wrap img{width:100%;height:100%;object-fit:cover;display:block}
.cam-overlay{position:absolute;inset:0;display:flex;align-items:center;justify-content:center;background:rgba(0,0,0,0.6);opacity:0;pointer-events:none;transition:opacity .2s}
.cam-overlay.on{opacity:1;pointer-events:auto}
.cam-overlay span{color:#fff;font-size:0.9rem;font-weight:600}
.cam-badge{position:absolute;top:10px;left:10px;background:rgba(0,0,0,0.7);color:var(--dim);font-size:0.65rem;padding:4px 10px;border-radius:6px;font-weight:600}
.cam-badge .rec{display:inline-block;width:7px;height:7px;border-radius:50%;background:#ef4444;margin-right:5px;animation:pulse 1.2s infinite}

/* Buttons */
.btn{padding:12px 20px;border-radius:10px;border:none;font-size:0.9rem;font-weight:700;cursor:pointer;transition:all .15s;display:inline-flex;align-items:center;justify-content:center;gap:8px}
.btn:disabled{opacity:0.5;cursor:not-allowed}
.btn-primary{background:linear-gradient(135deg,var(--accent),var(--accent2));color:#fff;box-shadow:0 4px 16px rgba(99,102,241,0.25)}
.btn-primary:hover:not(:disabled){transform:translateY(-1px);box-shadow:0 6px 20px rgba(99,102,241,0.35)}
.btn-primary:active:not(:disabled){transform:translateY(0)}
.btn-secondary{background:var(--surface2);color:var(--text);border:1px solid var(--border)}
.btn-secondary:hover:not(:disabled){border-color:var(--borderlt);background:#1e1e28}
.btn-cat{width:100%;padding:14px;border-radius:10px;border:none;font-size:0.9rem;font-weight:700;cursor:pointer;color:#fff;transition:all .15s}
.btn-cat:hover{transform:translateY(-1px)}
.btn-gen{background:linear-gradient(135deg,#dc2626,#ef4444)}
.btn-rec{background:linear-gradient(135deg,#d97706,#f59e0b)}
.btn-com{background:linear-gradient(135deg,#16a34a,#22c55e)}

/* Toggle */
.toggle{display:flex;align-items:center;gap:10px;cursor:pointer}
.toggle input{display:none}
.tog-track{width:44px;height:24px;border-radius:12px;background:var(--surface2);border:1px solid var(--border);position:relative;transition:.2s}
.tog-track::after{content:'';position:absolute;width:18px;height:18px;border-radius:50%;background:var(--dim);top:2px;left:2px;transition:.2s}
input:checked+.tog-track{background:rgba(99,102,241,0.2);border-color:var(--accent)}
input:checked+.tog-track::after{left:22px;background:var(--accent);box-shadow:0 0 8px var(--accent)}
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
void loop(){
  server.handleClient();
  updateServo();
  runLeds();
}

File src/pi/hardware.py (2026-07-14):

"""
AI Smart Bin - Raspberry Pi Hardware Layer

Real hardware control for:
- USB webcam (v4l2 mmap streaming — reliable on Pi 3B)
- Pan/tilt servos (pigpio - hardware timed PWM, no jitter)
- WS2812B LED ring (optional, not connected yet)
"""

import time
import threading
import subprocess
import logging

log = logging.getLogger(__name__)

# Servos - pigpio for hardware-timed PWM (no jitter)
try:
    import pigpio
    HAS_PIGPIO = True
except Exception:
    HAS_PIGPIO = False

# Pin config
PAN_PIN = 17
TILT_PIN = 27
LED_PIN = 18
LED_COUNT = 16

# pigpio pulsewidth range for servos: 500-2500us
# Map -1..1 to 500..2500, with 1500 as center
def _val_to_pw(value):
    return int(1500 + (value * 1000))

def _pw_to_val(pw):
    return round((pw - 1500) / 1000, 2)

# Bin presets — pan to the correct third, then tilt to dump
# Bin layout (top view): [ GENERAL | RECYCLING | COMPOST ]
#                        pan -1    pan 0       pan +1
#
# Tilt: 0.0 = horizontal (rest), -1.0 = fully tipped (dump)
# Used as fallbacks; live values come from the calibration store (database).
CATEGORY_PRESETS = {
    "general":   {"pan": -0.7, "tilt_dump": -0.6, "tilt_rest": 0.0},
    "recycling": {"pan":  0.0, "tilt_dump": -0.6, "tilt_rest": 0.0},
    "compost":   {"pan":  0.7, "tilt_dump": -0.6, "tilt_rest": 0.0},
}

# Timing
SORT_PAN_SETTLE_S = 0.5   # Wait for pan to reach position
SORT_DUMP_HOLD_S  = 1.0   # Hold tilt to let item fall
SORT_RETURN_S     = 0.5   # Wait for tilt to return

# Servo motion smoothing (slew-rate limiting).
# Manual control used to jump the pulsewidth straight to the target, which
# snaps the servos. The motion thread instead steps toward the target at a
# bounded rate so every move is smooth regardless of input source.
SLEW_ENABLED = True
SLEW_RATE = 2.5        # units/second (-1..1 scale); full sweep -1 -> +1 in 0.8s
SLEW_TICK_HZ = 50      # motion thread update rate

LED_COLORS = {
    "off": (0, 0, 0),
    "white": (32, 32, 32),
    "red": (255, 0, 0),
    "yellow": (255, 180, 0),
    "green": (0, 255, 0),
    "blue": (0, 0, 255),
    "purple": (128, 0, 128),
}


class Camera:
    """USB webcam capture using v4l2-ctl with mmap streaming.

    Keeps the camera device open for continuous frames and stable auto-exposure.
    """

    def __init__(self, device=0, width=640, height=480):
        self.width = width
        self.height = height
        self.device = device
        self._last_jpeg = None
        self._last_time = 0
        self._running = False
        self._process = None
        self._lock = threading.Lock()
        log.info(f"Camera: v4l2 mmap mode (device {device}, {width}x{height})")
        self._start_stream()

    def _start_stream(self):
        """Start v4l2-ctl mmap stream that keeps device open."""
        if self._running:
            return
        self._running = True
        self._thread = threading.Thread(target=self._stream_loop, daemon=True)
        self._thread.start()
        log.info("Camera: v4l2 stream started")

    def _stream_loop(self):
        """Run v4l2-ctl --stream-mmap and parse JPEG frames from output."""
        cmd = [
            "v4l2-ctl",
            f"--device=/dev/video{self.device}",
            f"--set-fmt-video=width={self.width},height={self.height},pixelformat=MJPG",
            "--stream-mmap",
            "--stream-count=-1",
            "--stream-to=-",
        ]

        while self._running:
            try:
                log.info("Camera: starting v4l2 stream...")
                proc = subprocess.Popen(
                    cmd,
                    stdout=subprocess.PIPE,
                    stderr=subprocess.PIPE,
                )
                self._process = proc

                # Read JPEG frames from stdout
                # JPEG files start with FF D8 and end with FF D9
                buffer = b""
                warmup = 5  # Skip first few frames for auto-exposure
                frame_count = 0

                while self._running and proc.poll() is None:
                    chunk = proc.stdout.read(4096)
                    if not chunk:
                        break
                    buffer += chunk

                    # Find JPEG frames in buffer
                    while True:
                        # Look for JPEG start marker
                        start = buffer.find(b"\xff\xd8")
                        if start == -1:
                            buffer = b""
                            break

                        # Look for JPEG end marker after start
                        end = buffer.find(b"\xff\xd9", start + 2)
                        if end == -1:
                            # Keep from start onwards, might be incomplete
                            buffer = buffer[start:]
                            break

                        # Extract complete JPEG frame
                        jpeg = buffer[start:end + 2]
                        buffer = buffer[end + 2:]
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

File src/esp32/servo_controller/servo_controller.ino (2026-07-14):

#include <WiFi.h>
#include <WebServer.h>

// ==================== CONFIG ====================
const char* ssid     = "YOUR_WIFI_SSID";
const char* password = "YOUR_WIFI_PASSWORD";
const int servoPin   = 13;          // PWM signal pin
// ================================================

WebServer server(80);

// MG996R: 50 Hz, 500us - 2500us pulse
// 16-bit resolution: duty = (us / 20000) * 65535
const int SERVO_MIN_US = 500;
const int SERVO_MAX_US = 2500;
const int PWM_FREQ     = 50;
const int PWM_BITS     = 16;
const int DUTY_MIN     = (SERVO_MIN_US * 65535) / 20000;  // ~1638
const int DUTY_MAX     = (SERVO_MAX_US * 65535) / 20000;  // ~8192

int currentAngle = 90;

void setServo(int angle) {
  angle = constrain(angle, 0, 180);
  int duty = map(angle, 0, 180, DUTY_MIN, DUTY_MAX);
  ledcWrite(servoPin, duty);
  currentAngle = angle;
}

void handleRoot() {
  String html = R"rawliteral(
<!DOCTYPE html>
<html lang="en">
<head>
<meta charset="UTF-8">
<meta name="viewport" content="width=device-width, initial-scale=1.0">
<title>ESP32 Servo Control</title>
<style>
  * { box-sizing: border-box; margin: 0; padding: 0; }
  body {
    font-family: 'Segoe UI', system-ui, sans-serif;
    background: linear-gradient(135deg, #1a1a2e 0%, #16213e 100%);
    color: #eaeaea;
    min-height: 100vh;
    display: flex;
    flex-direction: column;
    align-items: center;
    justify-content: center;
    padding: 20px;
  }
  .card {
    background: rgba(255,255,255,0.05);
    backdrop-filter: blur(10px);
    border: 1px solid rgba(255,255,255,0.1);
    border-radius: 24px;
    padding: 40px;
    width: 100%;
    max-width: 420px;
    text-align: center;
    box-shadow: 0 20px 60px rgba(0,0,0,0.4);
  }
  h1 { font-size: 1.6rem; margin-bottom: 8px; }
  .ip { color: #888; font-size: 0.85rem; margin-bottom: 28px; }
  .gauge-wrap {
    position: relative;
    width: 220px;
    height: 220px;
    margin: 0 auto 28px;
  }
  .gauge-bg, .gauge-fill {
    fill: none;
    stroke-width: 18;
    stroke-linecap: round;
  }
  .gauge-bg { stroke: rgba(255,255,255,0.08); }
  .gauge-fill {
    stroke: #00d4aa;
    stroke-dasharray: 345;
    stroke-dashoffset: 172;
    transition: stroke-dashoffset 0.3s ease, stroke 0.3s;
  }
  .gauge-text {
    position: absolute;
    top: 50%; left: 50%;
    transform: translate(-50%, -40%);
    font-size: 3rem;
    font-weight: 700;
  }
  .gauge-label {
    position: absolute;
    top: 65%; left: 50%;
    transform: translateX(-50%);
    font-size: 0.85rem;
    color: #888;
  }
  input[type=range] {
    -webkit-appearance: none;
    width: 100%;
    height: 8px;
    border-radius: 4px;
    background: rgba(255,255,255,0.1);
    outline: none;
    margin: 24px 0;
  }
  input[type=range]::-webkit-slider-thumb {
    -webkit-appearance: none;
    width: 28px; height: 28px;
    border-radius: 50%;
    background: #00d4aa;
    cursor: pointer;
    box-shadow: 0 0 12px rgba(0,212,170,0.5);
    transition: transform 0.1s;
  }
  input[type=range]::-webkit-slider-thumb:hover { transform: scale(1.15); }
  input[type=range]::-moz-range-thumb {
    width: 28px; height: 28px;
    border-radius: 50%;
    background: #00d4aa;
    cursor: pointer;
    border: none;
  }
  .presets {
    display: grid;
    grid-template-columns: repeat(5, 1fr);
    gap: 10px;
    margin-top: 12px;
  }
  .presets button {
    background: rgba(255,255,255,0.08);
    border: 1px solid rgba(255,255,255,0.12);
    color: #eaeaea;
    padding: 10px 0;
    border-radius: 12px;
    cursor: pointer;
    font-weight: 600;
    transition: all 0.2s;
  }
  .presets button:hover {
    background: #00d4aa;
    color: #111;
    border-color: #00d4aa;
  }
  .status {
    margin-top: 18px;
    font-size: 0.8rem;
    color: #00d4aa;
    opacity: 0;
    transition: opacity 0.3s;
    height: 1.2em;
  }
  .status.show { opacity: 1; }
</style>
</head>
<body>
<div class="card">
  <h1>MG996R Servo</h1>
  <div class="ip" id="ip">Connecting...</div>

  <div class="gauge-wrap">
    <svg viewBox="0 0 140 140" style="transform: rotate(135deg);">
      <circle class="gauge-bg" cx="70" cy="70" r="58"/>
      <circle class="gauge-fill" id="gauge" cx="70" cy="70" r="58"/>
    </svg>
    <div class="gauge-text" id="val">90°</div>
    <div class="gauge-label">ANGLE</div>
  </div>

  <input type="range" id="slider" min="0" max="180" value="90">

  <div class="presets">
    <button onclick="go(0)">0°</button>
    <button onclick="go(45)">45°</button>
    <button onclick="go(90)">90°</button>
    <button onclick="go(135)">135°</button>
    <button onclick="go(180)">180°</button>
  </div>

  <div class="status" id="status">Updated</div>
</div>
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

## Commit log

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2026-02-24 refactor: reorganise project structure, split docs, fix inconsistencies, scaffold for development
    - Add .gitignore for Python, ML models, binaries, and IDE files
    - Rewrite README.md with accurate project structure, hardware/software tables, and doc links
    - Slim down PLAN.md: extract budget, iteration log, and future scope into dedicated docs
    - Fix broken markdown bold syntax in PLAN.md (lines 24, 26)
    - Fix stale YOLO26 references in risk assessment and testing plan (now YOLO11s)
    - Add docs/README.md as documentation index
    - Add docs/03_budget.md (BOM and cost breakdown)
    - Add docs/04_iteration_log.md (YOLO11n vs YOLO11s iteration history)
    - Add docs/05_future_scope.md (Cloud VLM and TACO dat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
2026-02-24 feat: add ESP32 co-processor architecture, web dashboard, and UART serial protocol
    - Redesign system as dual-board: MaixCAM Pro (brain) + ESP32 (muscles) over UART
    - Add docs/06_serial_protocol.md with full command spec, timing, and sort sequence
    - Add web dashboard spec to PLAN.md (mode switching, live stats, camera, health, controls)
    - Update README.md with architecture diagram, dual-board tables, and dashboard section
    - Update BOM: add ESP32 DevKit (~.50), total now ~55 AUD
    - Update risk assessment: add UART failure, MaixCAM crash, Wi-Fi, and web access risks
    - Update testing plan: add UART reliability test and web dashboard responsiveness test
    - Rework future scope: Cloud LLM now integra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
2026-02-24 feat: redesign dashboard with LLM providers, webcam classification, and UV
    - Switch from pip/requirements.txt to UV with pyproject.toml (flask, httpx)
    - Add llm.py: multi-provider VLM abstraction (OpenRouter, OpenAI, Google Gemini, Custom)
    - Configurable API keys, model selection, and base URLs from the dashboard
    - System prompt for structured JSON waste classification
    - Automatic markdown fence stripping and response validation
    - Update database.py: add llm_providers table with CRUD, active provider toggle
    - Update app.py: add /api/classify (webcam photo classification), /api/providers CRUD
    - Redesign frontend with Alpine.js for full reactivity:
    - Dark grey/black theme with Inter fo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
2026-02-24 feat: overhaul web UI with Tailwind CSS, add settings save button, remove mock auto-sort
    Restyle the entire dashboard using Tailwind CSS (CDN) replacing 600 lines of
    custom CSS. Settings page now has an explicit Save button and free-text model
    ID input instead of a static dropdown. Mock mode no longer floods the database
    with fake sort events -- the auto-sort loop and simulate_sort() are removed.
    Provider preset model lists removed from llm.py since model selection is now
    freeform. Documentation updated to reflect the new frontend stack.
2026-02-24 fix: improve LLM error handling and add clear data button to settings
    Add detailed error messages for empty responses, invalid API keys, model
    not found, and rate limiting. Add /api/data/clear endpoint and Clear All
    Data button in settings with confirmation dialog. Database clear deletes
    all sort_events rows and resets stats to zero.
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2026-02-26 fix: make Ameru tray narrower and skeletonize mounting block
    [ameru_tray.scad]
2026-02-26 fix: restore floor of Ameru tray, prevent hollow block from cutting through surface
    [ameru_tray.scad]
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2026-02-26 feat: multi-item detection, ignore person/background, and JSON mode
    - VLM prompt now identifies ALL waste items in frame and returns an items array
    - Explicitly ignores people, hands, body parts, tray, and background
    - Added response_format: json_object for reliable JSON output
    - Backend logs each detected item as a separate sort event
    - Frontend displays each item with its own icon, category, and confidence
    - Empty result shows 'No waste items detected' instead of misclassifying
    - Classification history sidebar shows item count badge for multi-item captures
    - SSE handler expands multi-item events into individual activity entries
    - Icons resolved in parallel via fetchItemIcons for all detect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
2026-02-26 fix: classify any object, not just typical waste items
    The VLM was returning empty results for items like scissors because the prompt said 'only classify actual waste items'. Reframed to classify ANY object someone could put in a bin, including household items, tools, electronics, etc. Also expanded the general category definition to include mixed-material items, electronics, ceramics, and metal tools.
2026-02-26 fix: prevent Chart.js crashes when canvas is hidden on other tabs
    Chart.js throws TypeError when trying to update charts whose canvas elements are hidden (display:none) on non-dashboard tabs. _updateCharts() now skips updates when tab !== 'dashboard' and sets a _chartsDirty flag. A $watch on the tab property flushes deferred updates when switching back.
2026-06-06 feat: pi-prototype — Raspberry Pi 3B hardware + dashboard
    Hardware:
    - src/pi/hardware.py: real servo/camera/LED control via pigpio
    - Pan servo GPIO 17, Tilt servo GPIO 27, LED GPIO 18
    - pigpio hardware-timed PWM eliminates servo jitter
    - OpenCV threaded camera capture with fswebcam fallback
    - 1000µF capacitor on 5V rail for brownout protection
    Web:
    - PI_MODE flag in config.py for hardware switching
    - app.py: /api/servos/pan|tilt, /api/sort full pipeline, /api/camera/stream
    - pi_dashboard.html: simple functional dashboard with camera, d-pad, sort button
    Docs:
    - docs/pi_prototype_setup.md: full wiring diagram, SSH method, troubleshooting
    - docs/pi_prototype_todo.md: remaining tasks
    - docs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
    [ai_bin.js, ai_bin_c1_v2.js, ai_bin_c1_v3.js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]
2026-06-06 Full dashboard rewrite: HTMX+Tailwind, gamepad, bin presets, v4l2 stream
    Dashboard:
    - Complete rewrite with Tailwind CSS dark theme
    - Servo controls: d-pad, sliders, number inputs, keyboard, gamepad
    - LED ring UI (placeholder until wired)
    - System health monitoring (CPU temp, uptime, pigpio status)
    - Provider settings with connection test buttons
    - Dataset management (save/export/clear)
    - Activity log with SSE real-time updates
    - Debug panel with API tester and SSE event log
    Servo control:
    - Gamepad support (DualSense/Xbox) with deadzone filtering
    - Keyboard shortcuts (WASD, 1/2/3, H, Space)
    - Number inputs for precise pan/tilt values
    - Configurable nudge step (0.01, 0.05, 0.1, 0.25)
    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
    [hardware.py]
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2026-06-07 Face tracking with PID control, virtual joystick, continuous keyboard, auto-start
    Face Tracking:
    - PID controller (Kp=1.5, Ki=0.1, Kd=0.8) for smooth fast tracking
    - ROI (Region of Interest) for 3-5x faster detection after initial find
    - Haar cascade face detection via OpenCV
    - Green bounding box overlay on camera stream
    - Toggle with button or F key
    - Adjustable tracking speed slider
    - Tunable PID gains via API
    OpenCV Fix:
    - Removed apt python3-opencv (deadlocked on import)
    - Installed opencv-python-headless via pip (works fine)
    - cv2 now available for face detection
    - Virtual joystick (mouse/touch) for analog servo control
    - Arrow keys now work for servo control
    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
    [Connector+Generator.scad]
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2026-07-14 Backend: servo slew smoothing, animation engine, calibration API
    - hardware.py: 50Hz motion thread slews servos toward targets at a bounded
    rate so manual control no longer snaps; immediate=True bypass for the
    animation engine; get_position() exposes actual + target
    - animations.py: server-side keyframe playback (16 built-ins ported from
    the old client-side fun-controls) — smooth easing, survives tab close,
    loop support, SSE animation_state/servo_update events
    - Custom sequences: sequences table + CRUD via /api/animations/custom
    - Calibration moved to DB: GET/PUT /api/calibration, reset + per-category
    test endpoints; /api/sort now uses calibrated positions and timings
    - POST /api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
    [hardware.py]
2026-07-14 Frontend redesign: clean modern dark UI with XY pad control and new panels
    - New design system (app.css): zinc dark surfaces, Geist + Geist Mono,
    white primary actions, category colors reserved for waste categories,
    SVG icon sprite (no emoji icons), reduced-motion support
    - Servo control rework: XY drag pad with grid + position dot as the
    primary control, throttled sender (one coalesced POST per 60ms via
    /api/servos/move instead of per-pixel bursts), keyboard hold-to-repeat,
    gamepad routed through the same sender
    - Camera panel: cleaner toolbar, classification overlay, sort stage chip,
    model comparison modal ported from the old dashboard
    - New tabbed panels: Activity feed, Stats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
2026-07-14 Deploy script directory sync + docs updated for the redesign
    - deploy.py now walks src/pi + src/web instead of a hand-maintained file
    list (skips .venv, __pycache__, dataset, *.db); new files deploy without
    touching the script. Stale deploy.sh removed.
    - README rewritten for the Pi 3B standalone architecture and new dashboard
    - handoff.md, pi_prototype_setup.md, pi_prototype_todo.md updated: new
    endpoint table, animation/calibration docs, cv2 no longer a dependency,
    slew-smoothing flagged for a real-hardware test
2026-07-14 chore: scrub secrets from repo, untrack vendored .pio libs
    - Remove hardcoded Pi SSH password from deploy.py; read PI_HOST/PI_USER/
    PI_PASS from env, prompt for the password if unset
    - Replace real Wi-Fi SSID/passphrase in ESP32 sketches with placeholders
    - Genericise Pi IP / credentials in docs (handoff, setup, todo)
    - git rm --cached the 63-file .pio/libdeps ESP32 vendor tree and gitignore
    .pio/ so build artifacts stop getting committed
    Note: these values remain in prior git history (already pushed). Rotating
    the Pi password and Wi-Fi passphrase is the real fix.
    [main.cpp, servo_controller.ino, smart_bin_cam.ino]
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2026-08-04 cad: make the splitter print without supports, add STLs
    The one-piece hub needed supports right through the pipe bores, and
    support scarring in a bore wrecks the fit. Split into a flat plate plus
    three brackets and three clamps, all of which print in their natural
    orientation with no supports at all.
    Pipe bores are teardrops so a sideways hole self-supports. Feet bolt
    through the plate with countersunk screws instead of on ears, which
    keeps the plate at 131mm so it fits a 180mm bed.
    Fixes found while checking the renders:
    - teardrop peak pointed sideways instead of up, so it did nothing
    - teardrop poked out through the top of the socket block
    - clamp jaws straddled the wrong axis; the bin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
    [bracket.stl, clamp.stl, plate.stl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]
2026-08-06 cad: line-contact jaw so the clamps fit a rectangular bin, halve filament
    Two of the three clamps did not fit. Legs sit 120 degrees apart, so on a
    rectangle only one can meet its wall square on. For the ecobin the other
    two are 30 degrees off, which shifts the wall 15mm across a 26mm jaw with
    a 9mm gap, so they would have jammed on opposite corners.
    This is geometry, not tuning: you cannot make three legs at 120 degrees
    all land square on a rectangle. So the fixed jaw is now a vertical rounded
    rib that touches along a line, with the thumbscrew pushing a single point
    opposite it. A line plus a point pinches at any angle, which also means the
    same clamp now works on a round bin or a cardboard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
    [bracket.stl, clamp.stl, plate.stl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]
2026-08-06 cad: narrow the outer jaw, auto-size pipes from bin dimensions
    The rib fixed WHERE the jaw touches a skewed wall but not whether the wall
    could physically get in. A 4.5mm wall at 30 degrees sweeps 16.7mm sideways
    across a 20mm jaw with only 10mm of clear gap, so it still jammed. Outer
    jaw is now a 9mm post and the gap is derived from the worst case rather
    than guessed, so it clears an 8mm wall at full skew.
    Bin dimensions are now inputs. The preview works out each leg's reach and
    echoes its own pipe length, so the three legs are no longer assumed equal:
    leg 60 -> 154.7mm -> cut 104mm
    leg 180 -> 169.0mm -> cut 119mm
    leg 300 -> 154.7mm -> cut 104mm
    The preview also draws the bin, which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
    [bracket.stl, clamp.stl, plate.stl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]
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2026-08-06 cad: tray is a rimless saddle, matching the Ameru reference
    The bowl version was wrong. It grew a 22mm rim, which is exactly what you
    do not want: a wall that traps the item at the moment you are trying to
    tip it out. The Ameru tray has no rim at all, the surface just runs out to
    a thin edge, and it is a saddle rather than a dish.
    So: hyperbolic paraboloid, no rim anywhere.
    sides curl UP 10mm the pan sweep throws the item along this axis and
    the valley rolls it back to the middle. Retention
    by gravity instead of by a wall.
    ends curl DOWN 5mm where it leaves. Nothing to climb at all.
    Ends are only 9.5 degrees, well under the ~19 wher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
    [tray.scad, tray.stl]
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2026-08-10 cad: correct the screw lengths, and have the model work them out
    The hardware list called for M3 x 12 into the bracket feet. With an insert in
    the foot there is only 9mm of depth there, so a 12 would bottom out on the
    build plate side and never pull the joint tight. It wants an 8. The pipe locks
    and the tab screws were over-specified the same way, 12 and 10 where 8 does it.
    The list was written by hand and drifted from the geometry, so rendering now
    echoes the lengths instead: foot 8 to 9mm, pipe lock 7.7mm, tab 5.2mm, and the
    thumbscrew worked out from the actual jaw gap and bin wall.
    Comments and echoes only. No geometry changed, so the STL and STEP exports and
    the Fusion models are all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
    [splitter_hub.scad]
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2026-08-10 cad: the thumbscrew calc forgot the rib radius, and note the standoff option
    jaw_gap is measured from the rib's centre, so the opening a thumbscrew has to
    cross is jaw_gap - rib_r. The echo used jaw_gap, overstating every thumbscrew
    by a whole 3mm rib radius. That is what made this ask for an M3 x 25 it never
    needed. Checked against the mesh by casting a ray down the screw axis: clear
    opening 13.124mm, screw touches a 4.5mm wall at 13.624mm, and the corrected
    echo now prints exactly that. M3 x 16 has 2.4mm of travel, M3 x 20 has 6.4mm.
    Which also means the earlier bin_wall_max 8 -> 6 was not needed to reach an
    M3 x 20. Keeping it anyway: the ecobin is 4.5mm and cardboard is 3 to 6, so 6
    is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
    [splitter_hub.scad, tray.scad]
2026-08-10 cad: the retaining tabs were 0.25mm too tight for the real pan-tilt base
    Sonny supplied the pan-tilt as a STEP. Its base measures 125.00mm dead. base_dia
    was 124.5, taken off the real thing with calipers, which put the plate's three
    retaining tabs 0.25mm inside the base on every side. It would not have dropped
    in, and that is not something you notice until both parts are printed and in
    your hands.
    base_dia is now 125.6, so 0.3mm a side to seat. The plate grows to 132mm and the
    bracket feet move out with it; the clamps do not move, because the bin wall did
    not. Pipes come down to 103.73 / 118.00 / 103.73mm.
    Also adds four renders of the whole thing for the portfolio, generated straight
    out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
    [plate.step, plate.stl, splitter_hub.scad]
2026-08-10 portfolio: regenerate the renders from the corrected assembly
    The Fusion assembly had silently rolled back. Moving a component in a
    parametric assembly is a position change, and Fusion discards those on the next
    rebuild unless they are captured as a snapshot. Every reposition this session
    was applied and then quietly reverted: the tracker sat at its imported height
    instead of on the plate, the tray hung at the old placeholder height, and the
    bracket feet were back at the pre-fix radius.
    Positions are now captured as snapshots, so they survive a rebuild. The tracker
    was also re-imported whole, so the mount plate is back.
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2026-08-10 cad: tray mount replaces the spacer block, and it is modelled in Fusion
    The spacer could not be bolted on. The tilt arm offers two M3 holes 15mm apart
    on a 19 x 34mm face; the tray wants four on a 32 x 15 pattern. Nothing lined up,
    and two screws in a line would have let the tray rock anyway.
    The mount is a cap. Its socket drops over the end of the tilt arm, so the arm
    stops the tray twisting rather than the screws having to. The top plate carries
    the tray's four holes and, being wider than the arm, moves the tray back over
    the pan axis, which sits 6.5mm off the arm's mounting face. Print it upside
    down and every overhang faces the bed.
    Height came out of a real check rather than a guess.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
    [tray_mount.step, tray_mount.stl]
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2026-08-10 cad: resize the mount plate so it stops looking crooked
    The plate was centred on the tilt arm and the tray's boss is centred on the pan
    axis, and those are 6.5mm apart, so from underneath the two rectangles sat
    visibly offset. Functionally fine, since all four bolts were inside both, but it
    read as a mistake.
    The plate is now 52 x 45 centred at y = -4.75, chosen to contain both
    footprints. X is 52, which is the boss exactly, so those edges line up on
    purpose. Y runs -27.25 to 17.75, reaching far enough to cover the socket at
    -26.8 and the boss at 17.5.
    The offset cannot be designed away, because the arm genuinely sits 6.5mm off the
    pan axis. Containing both footprints is what makes it look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
    [tray_mount.step, tray_mount.stl]
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2026-08-11 cad: draw the current version of each part from Fusion, not the .scad
    The evolution renders had every "current" panel coming from the OpenSCAD
    working copy, which is no longer the design source. Nothing had actually
    drifted, but the pictures would have gone stale silently the first time a
    part changed in Fusion, which defeats the point of having them.
    Checked before changing anything. Fusion and the .scad files agree to within
    0.15% on volume, all bounding boxes identical, and the gap is OpenSCAD
    approximating curves with flat facets:
    part Fusion .scad gap
    plate 32490.3 32443.1 0.15%
    bracket 16137.2 16156.1 0.12%
    clamp 17478.3 17496.2 0.10%
    tra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
    [bracket.step, bracket.stl, clamp.step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]
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2026-08-11 cad: camera head, and the post standing in the assembly
    The webcam has a 1/4-20 tripod thread, which beats clipping it to a fake
    monitor edge, so the head carries a 1/4-20 bolt: clearance hole through a side
    arm with an 11.5mm recess underneath for the head, thread pointing up. The arm
    sticks out toward the tray, which keeps the pipe out of shot and leaves the
    bolt head reachable from below. Verified at 18806.1 mm3, 0.000% off the
    calculated figure, and the STL agrees to 0.01%.
    Now actually in the assembly, which it was not before:
    - camera clamp inserted on the transform of the 180 degree clamp it replaces,
    and that plain clamp removed
    - 300mm of 20mm conduit from z=-5 up to z=295
    - head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
    [camera_head.step, camera_head.stl]
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2026-08-11 cad: the bought pan-tilt stacked two servos, so the tray sat 147mm above the rim
    The MakerWorld tracker puts the tilt servo on end inside a U-bracket, with
    its body 37mm above the tilt axis, so the tray has to clear the servo before
    it can clear anything else. 85mm of the 147mm from the bin rim to the tray
    was that stacking.
    Replaced it with three printed parts and a change to the hub plate:
    pan ring traps the pan servo's flange against the plate and carries
    the yoke's bearing. No screws into the servo: the two
    published figures for the MG996R flange pattern disagree by
    1.5mm, so nothing depends on it.
    tilt yoke carries the tilt servo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
    [pan_ring.step, pan_ring.stl, plate.step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]
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2026-08-11 Revert "portfolio: a Build Logs section at the end for work done since submission"
    This reverts commit 719a00b852230ad1efa575117fb08728ccce6fa5.
    [ai_bin.js]
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2026-08-11 cad: the camera head's bolt recess was on top, so the webcam hung inverted
    The head is modelled with its pipe socket growing upward and then flipped in the
    assembly to drop over the post, so the face the sketch sits on becomes the arm's
    top. Both cuts started 1mm back from that plane: the 6.6mm clearance hole ran
    10mm and went clean through the 8mm arm, and the 11.5mm head recess ran 5mm and
    stopped 4mm in. Right depth, wrong end. The thread pointed down, so a webcam,
    whose tripod socket is underneath, would have hung below the arm upside down and
    every frame would have arrived rotated 180 degrees.
    The recess now starts 4mm along instead of 1mm back, so the same pocket opens on
    the undersid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
    [camera_head.step, camera_head.stl]
2026-08-11 cad: the pipe sockets were a round bore in a solid block, mostly corner
    Every part that holds a pipe did it the same way: a 343 mm2 teardrop bore
    through a 663 mm2 solid wedge. That is 36% plastic and 64% air, and the plastic
    was in the wrong place, 1.49mm of wall at the equator and 6mm sitting in the
    corners doing nothing. A rectangle was only ever what you get from extruding a
    rectangle.
    The outer face now follows the bore, offset 2.5mm, with 45 degree flanks so it
    still prints without support. Built as a subtraction from the old outline, so
    the parts can only shrink and no clearance in the assembly can change.
    bin clamp x2 17,478 -> 13,709 mm3 -21.6%
    camera clamp x1 30,919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
    [bracket.step, bracket.stl, camera_clamp.step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]
2026-08-11 cad: the Pi and the breadboard had nowhere to live, so they sat loose on a desk
    Two new parts, both outside the bin, neither of which changes an existing one.
    A box hanger hooks over the rim and carries the weight on the rim itself rather
    than on a friction pinch: one hanger holding 300g on a 33mm arm is not the same
    problem as three clamps sharing a tripod. Its jaw is the bin clamp's rib and
    thumbscrew, so it still grips a rectangular bin, a round bin or a box.
    An electronics box, 185 x 62 x 40mm inside, hangs on the hanger's 45 degree
    cleat and lifts straight off. A Pi 3B and a half-size breadboard lie side by
    side on four pegs that match the Pi's own hole pattern.
    Underneath the hub wa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
    [box_hanger.step, box_hanger.stl, electronics_box.step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]
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2026-08-11 cad: the crash left the plate and the yoke rolled back, and the post had no lock
    The hub plate's feature history was what the crash destroyed, so it is rebuilt
    natively rather than imported: reading the committed STEP's faces gave the
    design back exactly, and it was then drawn from those numbers as seven features.
    28295.24 mm3 against the committed 28295.2, same 45 faces, same face areas to
    0.01 mm2.
    The tilt yoke was missing 149.50 mm3. Comparing it to the committed STEP face by
    face located it as a 20 x 3.25 x 2.30mm notch, which is fault 12's relief for
    the tilt servo flange. Putting it back brings the yoke to 39312.94 against the
    committed 39312.94, and re-exporting now produces an STL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
    [camera_clamp.step, camera_clamp.stl, plate.step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]
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
